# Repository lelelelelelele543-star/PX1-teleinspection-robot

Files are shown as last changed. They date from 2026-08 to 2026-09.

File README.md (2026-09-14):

# PX-1 Teleinspection Robot

## Текущий комплект

Единственный действующий master и документация: [current/](current/README.md).

Механический эталон — Proteus CRP-150. Электроника собственная, на готовых модулях. Текущий статус: **HOLD — рабочая конструкция к изготовлению не выпущена**. Успех CAD-экспорта не означает PASS механики.

- [Общий STEP](current/CAD/PX1_Current_Master.step)
- [Текущая BOM](current/PX1_Current_BOM.csv)
- [Validation](current/PX1_Current_Validation.json)
- [Чертежи и CAD-виды](current/PX1_Drawings_Current.pdf)
- [PDF-документация](current/PX1_Documentation_Current.pdf)
- [Электрические соединения и распиновки](current/ELECTRICAL_Current.md)
- [Сборка, герметизация и испытания](current/ASSEMBLY_AND_TESTS_Current.md)
- [Источники размеров](current/SOURCE_REGISTER.md)
- [Журнал изменений](current/PX1_Change_Log.md)

Шесть колёс; станции X50/X150/X250; десять Z50; два двигателя; Z16→Z40→задняя ось→Z50. Ручной лифт, отдельная герметичная камера, съёмный PRESSURE/LIFT. Оба кабеля ровно шестижильные; основной tether без коаксиала. Своей PCB, кассет и внешних шарниров открытия корпуса нет.

Предыдущие Rev и WB сохранены как история. Их пометки active/PASS не имеют приоритета над current. Перед любым изготовлением сверять HOLD и исходный SHA в validation.

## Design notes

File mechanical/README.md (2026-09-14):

# PX-1 Mechanical CAD — current Rev.B

The controlling mechanical artifact is now one integrated crawler master rather than a chain of exploratory sub-studies.

## Current master

- engineering note: `PX1_CURRENT_MASTER.md`
- executable CAD: `cadquery/PX1_Current_Master_RevB.py`
- executed check: `cadquery/PX1_CURRENT_MASTER_VALIDATION.json`
- generated output: `PX1_RevB_Current_Master.step`

Status: **PASS_INTEGRATED_MASTER / WHEEL_GEOMETRY_DN150_HOLD / PRESSURE_TEST_HOLD / PROCUREMENT_HOLD**.

## Hard crawler architecture

- 3 wheel stations per side / 6 wheels total;
- X50 / X150 / X250;
- five m1 Z50 gears per side / ten total;
- two traction motors total;
- rear X250 long axle is the drive input on each side;
- manual camera lift;
- dry pressurized crawler body;
- separately sealed removable camera;
- no mechanical cassette/cartridge architecture.

## Source-derived assembly

The current master combines the recovered Proteus logic in one model:

- `DRW-002-374` side drive;
- `DRW-002-375` crawler housing / Z40 input / seals;
- `DRW-002-386` two-motor Z16 input;
- `DRW-002-744` manual lift / 150 N gas spring principle;
- `DRW-002-745`, `DRW-002-752`, `ASS-002-890` pressure/lift/camera service interface;
- `ASS-002-090`, `ASS-002-364` rear connector and cable strain-relief logic;
- `ASS-002-103` wheel lock assembly.

Where an original proprietary component is unavailable, the replacement is fitted into the same functional location rather than inventing a different crawler architecture.

## Current geometry

- body main screen 307 x 92 mm;
- rear motor housing end X384;
- wheel stations X50/X150/X250;
- Z50 stations X50/X100/X150/X200/X250;
- lift pivot X200;
- lift pivots Z92/Z109;
- links 90 mm;
- arm planes Y±31 mm;
- camera shell Ø52 x 78 mm;
- service cover 86 x 44 x 6 mm;
- opening 48 x 22 mm;
- flush pressure cap envelope Ø12 x 1.5 mm;
- M12 harness gland horizontal;
- camera harness exactly 6 insulated conductors, hard OD max 6.5 mm;
- lift harness guard envelope 10 mm.

## Six-core camera/lift interface

Exactly:

`+12V / GND / UART TX / UART RX / CVBS signal / CVBS return`.

Dry connector candidate: Molex Micro-Fit 3.0 six-way.

Wet camera connector: WEIPU SP13 six-pin.

No 8-core wet lift harness is controlling.

## Wheel rule

The master displays simple Ø90 x 16 cylinders only as visual wheel placeholders. They are not a valid production tire/profile solid and are excluded from final DN150 geometry release.

MiniCam currently specifies `QRW90SR/150` 90 mm wheels for 150 mm pipe. Final wheel release requires the purchased/measured wheel or exact missing outer-profile drawing/solid plus a physical DN150 jig.

Do not redesign the crawler around the simple cylinder proxy.

## Release rule

The integrated master is suitable for continuing design and prototype packaging, not for machining release.

Before manufacturing release it still needs:

- exact wheel profile;
- matched Z16/Z40 bevel hardware;
- exact pressure seal groove from the real elastomer;
- pressure decay/submersion test;
- six-core cable flex/EMC test;
- physical connector pin orientation;
- exact rear tether-tail dimensions;
- physical DN150 validation.

Historical WBxx files remain in the repository only as calculation/revision traceability. New work should update the current integrated master rather than creating a new crawler architecture.

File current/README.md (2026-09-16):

# PX1 Current

Единственный текущий комплект. Механический эталон Proteus CRP-150; собственная электроника на готовых платах.

## Rev.A fast-track

**Rev.A обязательно шестиколёсный. 4-колёсный вариант не является допустимым упрощением.**

Активный порядок разработки описан в [REV_A_FAST_TRACK.md](REV_A_FAST_TRACK.md).

Рабочие пакеты:
- [00_PROJECT_CONTROL](00_PROJECT_CONTROL/README.md)
- [01_MECHANICAL_6X6](01_MECHANICAL_6X6/README.md)
- [02_ELECTRICAL](02_ELECTRICAL/README.md)
- [03_FIRMWARE](03_FIRMWARE/README.md)
- [04_CAMERA_HEAD](04_CAMERA_HEAD/README.md)
- [05_TETHER_REEL](05_TETHER_REEL/README.md)
- [06_CONSOLE](06_CONSOLE/README.md)
- [07_TESTS](07_TESTS/README.md)
- [08_PROCUREMENT](08_PROCUREMENT/README.md)
- [09_RELEASE](09_RELEASE/README.md)

## Current engineering baseline

- CAD/PX1_Current_Master.py — единственный исходник текущей сборки.
- CAD/PX1_Current_Master.step — экспорт после успешной сборки.
- PX1_Current_BOM.csv — единая BOM.
- PX1_Current_Validation.json — проверка конкретного экспорта; старые результаты не переносить.
- PX1_Change_Log.md — единый журнал изменений.
- SOURCE_REGISTER.md — источники размеров и границы достоверности.
- ELECTRICAL_Current.md — схемные соединения и логические распиновки.
- ASSEMBLY_AND_TESTS_Current.md — герметизация, давление, сборка, обслуживание, испытания.
- PX1_Drawings_Current.pdf / PX1_Documentation_Current.pdf — текущие документы.

Frozen crawler architecture: six wheels; stations X50/X150/X250; ten Z50 total; two traction motors; Z16→Z40→rear X250 axle→Z50 train. Manual lift, separately sealed camera, reinforced six-core main tether without coax, no custom main PCB required for the first prototype.

`Metal_HOLD` and unresolved CAD remain prototype-only. A successful CAD export is not an engineering PASS. Historical WB/Rev files are retained as history and cannot override `current/`.

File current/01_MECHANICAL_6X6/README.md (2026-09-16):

# 01 MECHANICAL — 6×6 CRAWLER

Scope: body, side drives, shafts, gears, bearings, seals, six wheels, motor mounting, manual lift mechanical interfaces.

Frozen topology: 3 wheel stations per side at X50/X150/X250; 5×Z50 per side; rear X250 driven input; two motors total; Z16->Z40 bevel input.

Immediate work:
1. lock motor mounting that physically fits the recovered Proteus envelope;
2. lock Z16/Z40 matched bevel pair and mounting distance;
3. finish shaft/bearing stack dimensions;
4. produce printable/fabricable A0 drivetrain bench parts;
5. assemble full six-wheel rolling chassis only after A0 passes.

Do not release metal machining while any critical shaft, gear mesh, bearing seat or seal groove dimension is HOLD.

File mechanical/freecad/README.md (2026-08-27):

# FreeCAD workflow for PX-1

## First model
1. Open FreeCAD and create a new document.
2. View -> Panels -> Python console.
3. Run `PX1_Master_Parameters.py`.
4. Run `PX1_Body_Master.py`.
5. Save as `PX1_MASTER.FCStd`.

The model is parameter-driven. Change dimensions on the `PX1_Parameters` object instead of editing geometry directly.

## Frozen prototype baseline
- body 250 x 94 x 76 mm
- wheelbase 160 mm
- wheel diameter 90 mm
- front axle X=45 mm
- rear axle X=205 mm
- axle Z=37 mm
- only two rear rotating body penetrations
- rear carrier bore Ø38 mm
- shaft Ø10 mm
- 6000 bearing: 10 x 26 x 8 mm
- seal: 10 x 22 x 7 mm

## Important
The rear LEMO opening in this model is only the controlled nominal interface envelope. Do not use generated thread geometry as a substitute for the official connector machining requirements.

Next FreeCAD components will be linked to the same master parameter object: rear carrier, output shaft, front stub axle, drivetrain gears, wheel, motor cradle, camera lift and camera head.

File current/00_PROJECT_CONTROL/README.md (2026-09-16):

# 00 PROJECT CONTROL

Single control point for PX1 Rev.A.

Authoritative working plan: `../REV_A_FAST_TRACK.md`.

Rules:
- 6×6 architecture is frozen;
- `current/` is the only active product set;
- historical WB/Rev files are evidence/history, not controlling geometry;
- every unresolved manufacturing dimension remains HOLD;
- every change that affects interfaces is recorded in `../PX1_Change_Log.md`;
- do not start a new concept to bypass a difficult detail.

Stage gates: A0 drivetrain bench -> A1 rolling chassis -> A2 tether -> A3 camera/lift -> A4 demo -> A5 endurance -> A6 production release.

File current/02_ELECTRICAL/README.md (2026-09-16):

# 02 ELECTRICAL

Scope: 24 V input, DC/DC rails, traction drivers, MCU, RS-485, pressure sensing, lighting supply/control, camera power/video interfaces, protection and connectors.

Prototype principle: ready-made serviceable modules, no custom main PCB required.

Immediate work:
1. bench power tree;
2. two traction channels under real motor load;
3. RS-485 command link;
4. emergency/communication-loss motor stop;
5. pressure input;
6. camera + lighting integration;
7. 40 m tether voltage-drop/EMC test.

Existing `../ELECTRICAL_Current.md` remains the detailed electrical reference until replaced by verified measurements.

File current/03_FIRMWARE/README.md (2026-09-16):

# 03 FIRMWARE

Rev.A firmware is intentionally minimal.

First required functions:
- forward/reverse;
- differential steering;
- speed command;
- traction stop on lost communications;
- light level command;
- pressure telemetry;
- basic fault/status telemetry.

After the crawler physically drives through the tether, add distance/OSD/operator conveniences. Do not block A0/A1 mechanics waiting for advanced UI features.

Recommended split:
- `crawler/` — STM32 traction/telemetry firmware;
- `console/` — operator controls/protocol;
- `protocol/` — one documented RS-485 packet definition shared by both ends.

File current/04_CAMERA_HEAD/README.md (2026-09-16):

# 04 CAMERA HEAD + MANUAL LIFT

Scope: sealed camera head, CVBS module, white LEDs, local six-conductor harness, PAN/ROTATE only when required by the selected head implementation, and manual Proteus-style lift.

Fast-track requirement: a stable forward inspection image is more important than completing every final camera feature before A4.

Gate for A3:
- stable image under traction motor operation;
- usable illumination;
- separately sealed/removable head;
- low/high manual lift positions;
- harness routing survives repeated movement without pinching or rubbing.

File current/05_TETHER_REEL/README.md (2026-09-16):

# 05 TETHER + REEL

Main tether architecture is frozen: professional reinforced six-core copper inspection cable, no coax in the main tether, field-reterminable, tensile load carried mechanically rather than by contacts.

Fast-track:
- first system length: 40 m;
- qualify conductor resistance, loaded voltage drop, RS-485 and video behaviour before 100–150 m design;
- temporary/manual cable handling is acceptable for A4 if safe and reliable.

RMP300-style reel, levelwind, brake, measuring wheel and slip ring are retained as the production direction but may not block first crawler demonstration.

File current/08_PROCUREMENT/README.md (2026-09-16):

# 08 PROCUREMENT

Procurement is stage-driven.

Buy first only what is required for A0/A1/A2:
- two traction motors matching the selected mount;
- matched bevel gears/shaft hardware;
- Z50 gears or fabrication material;
- bearings/bushings/seals for one complete crawler;
- six wheel samples/approved wheel solution;
- MCU + two traction drivers + RS-485 + DC/DC/protection;
- enough six-core tether for the 40 m prototype plus termination allowance.

Camera/reel/production cosmetics are second wave unless needed to unblock interface dimensions.

Every ordered item must be entered in `../PX1_Current_BOM.csv` with exact article, quantity, dimensions/source and its release/HOLD state.

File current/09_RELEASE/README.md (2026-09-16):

# 09 RELEASE

This folder is the gate to fabrication/production, not a dumping ground for experimental CAD.

A6 release requires:
- proven 6×6 crawler geometry;
- exact bought-part articles and measured/official envelopes;
- no critical machining dimension marked HOLD;
- released STEP/STL and part drawings;
- released BOM;
- electrical pinout and wiring;
- firmware version/protocol reference;
- assembly/disassembly procedure;
- sealing procedure;
- test acceptance sheet.

Until these conditions are met, project status remains prototype/HOLD.

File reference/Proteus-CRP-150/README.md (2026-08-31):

# Proteus CRP-150 reference reconstruction

Status: active engineering reference, revision 0.1, 2026-08-31.

This directory collects verified information about the Mini-Cam Proteus CRP-150 crawler system and separates it from the PX1 replacement design. Its purpose is to preserve the proven Proteus architecture while identifying replacements that can be purchased, machined, printed and serviced without proprietary Mini-Cam parts.

## Project rule

Every statement is assigned one of four evidence states:

- `CONFIRMED-DRAWING` - explicitly shown in an available source drawing or parts list;
- `CONFIRMED-PHOTO` - visible in repair photographs or video;
- `RECONSTRUCTED` - derived from several confirmed facts and engineering geometry;
- `PROVISIONAL` - a candidate that still requires measurement or a bench test.

Original Mini-Cam drawings are not stored here. The available drawings contain restrictions on copying and distribution, and this repository is public. This directory stores source identifiers, engineering facts, calculations and original reconstruction work only.

## System map

| Subsystem | Original reference | Replacement goal | Current state |
|---|---|---|---|
| Crawler body and drive | CRP-150 / X200 | Preserve six-wheel, five-gear side drive and two-motor bevel input | Drive architecture confirmed |
| Manual lift | CRP-150 lift | Preserve manual lift, 150 N spring and M8 clamp | Source set identified |
| Camera | CAM026 | Preserve sealed PAN/ROTATE behavior with available camera and motors | Pending detailed reconstruction |
| Cable reel | RMP300 | Preserve manual drum, brake, level wind, measuring wheel and slip ring | Source set identified |
| Control unit | Proteus portable control unit | Rebuild from replaceable 24 V modules | Functional requirements established |
| Tether | Proteus inspection cable | Reinforced, field-repairable six-core copper cable | Architecture fixed; conductor sizing pending |

## Directory map

- [`SOURCE_REGISTER.md`](SOURCE_REGISTER.md) - source identifiers and evidence limits;
- [`VERIFICATION_REGISTER.md`](VERIFICATION_REGISTER.md) - open measurements and proof status;
- [`crawler/DRIVE_ARCHITECTURE.md`](crawler/DRIVE_ARCHITECTURE.md) - confirmed CRP-150/X200 drive reconstruction;
- [`crawler/GEAR_AND_SHAFT_AUDIT.md`](crawler/GEAR_AND_SHAFT_AUDIT.md) - calibrated gear geometry and CAD conflict audit;
- [`replacement-parts/STRATEGY.md`](replacement-parts/STRATEGY.md) - rules and first replacement matrix;
- `cad/reconstruction/` - only original reconstruction CAD, never copied factory drawings;
- `camera/`, `lift/`, `reel/`, `control-unit/` - subsystem work areas.

## Fixed project constraints

- preserve the successful Proteus mechanical architecture unless availability, serviceability, cost, reliability or manufacturability justifies a change;
- use integrated serviceable assemblies, not cartridge or cassette concepts;
- prototype electronics use ready-made modules; no custom main PCB;
- internal robot power is 24 V class;
- main tether is one professional reinforced six-core copper inspection cable;
- no coaxial main cable, no optical fiber and no bundle of loose ordinary twisted pairs;
- keep a universal sealed quick-release tail connection with a separate mechanical strength path;
- do not release machining drawings until one side drive, one camera axis and the reel counter mechanism are physically proven.

## Current priority

1. Complete the original crawler skeleton and shaft stack.
2. Select an available 24 V traction motor that preserves the Z16 to Z40 input.
3. Validate the five-Z50 side drive and wheel speed.
4. Reconstruct the manual lift.
5. Continue with CAM026, RMP300 and the control unit.

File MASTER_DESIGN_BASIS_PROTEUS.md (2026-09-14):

# PX-1 MASTER DESIGN BASIS — Proteus CRP-150 replacement system

Status: ACTIVE MASTER DIRECTIVE.

## Mission
Build a serviceable, lower-cost teleinspection system that preserves the proven MiniCam Proteus CRP-150 / CAM026 / RMP300 user experience and mechanical logic while replacing proprietary, obsolete, expensive or hard-to-source parts with readily available equivalents.

This document supersedes earlier experimental PX1 concepts where they conflict with the Proteus-reference architecture.

## System-level rule
Preserve where possible:
- crawler external form and DN150-class packaging;
- six-wheel crawler layout;
- three driven wheel stations per side;
- five equal side gears per side;
- rear wheel long-axle input architecture;
- Z16 -> Z40 bevel input with two motors total;
- manual camera lift with 150 N gas spring and M8 clamp;
- compact removable pressure/lift service interface with local cable gland and protected camera harness;
- CAM026-like 360-degree ROTATE and +/-135-degree PAN envelope/function;
- lightweight manual RMP300-style reel with level-wind, brake, measuring wheel and slip-ring path;
- simple portable control console workflow.

Change where needed:
- motors;
- controller electronics;
- motor drivers;
- video electronics;
- pressure sensor electronics;
- connectors;
- slip ring;
- distance encoder;
- bearings/seals only when original sizes are unavailable or a direct standard replacement is preferable;
- camera imaging module and focus system.

## Crawler baseline
Source references: DRW-002-374, DRW-002-375, DRW-002-386.

Active side-drive topology, each side:
- wheel Z50;
- idler Z50;
- wheel Z50;
- idler Z50;
- driven rear wheel Z50 on long axle.

The rear wheel is the driven input station. There is no separate fourth input shaft.

Source bearing/seal architecture per side:
- 1x 61801-class bearing on long-axle/input path;
- 3x 61903-class wheel bearings;
- 3x X-ring 18.72x2.62;
- 3x static axle-flange O-rings 32x1.5;
- side-cover O-ring 190x1.5;
- two small idler bushings 10-12-4.

Main crawler body source architecture:
- 2x Z40 large bevel gears;
- 2x 18x30x7 shaft seals;
- 2x 61800 10x19x5 bearings;
- lift holding/axle parts integrated into body.

Motor unit source architecture:
- 2 motors total;
- 2x Z16 small bevel gears;
- 2x supported bevel pinion shafts;
- 2x 61801 bearings.

Official CRP-150 control envelope used as target reference: about 307 x 133 x 110 mm.

## Manual lift baseline
Source: DRW-002-744.

Retain:
- 1x gas spring 150 N;
- 2 side levers;
- lever sheet plate;
- M8 clamping lever;
- Belleville spring stack;
- source-style axle/washer/circlip arrangement.

Do not invent new powered lift mechanisms unless the manual source architecture proves impossible to reproduce.

## Pressure/lift service interface baseline
Sources: DRW-002-745, DRW-002-752, ASS-002-890, DRW-003-121 / ASS-003-121 and CRP150 repair photographs.

Retain the functional logic:

`dry pressure body -> removable sealed service cover/lift housing -> compact pressure/fill valve -> local M12-class cable gland -> short protected camera harness -> removable camera connector`.

Current PX-1 Rev.B implementation is controlled by WB23E/F/G:

- WB22A hard lift geometry remains unchanged;
- body lift pivot remains X200;
- no mandatory dual flex chambers or energy-chain style loops;
- service cover is WB23E 86 x 44 x 6 mm with 48 x 22 mm opening and two-M4 prototype retention;
- pressure-port procurement follows WB23F: preferred exposed valve+cap envelope <=Ø12 x 5 mm, current hard screen <=Ø14 x 6 mm;
- local wet camera/lift harness is exactly **six insulated conductors**: +12V, GND, UART TX, UART RX, CVBS signal, CVBS return;
- overall cable shield is EMC only and never DC power return;
- local cable target is 6 x 0.25 mm² class, preferred OD 5.5...6.0 mm, hard packaging maximum 6.5 mm;
- lower-arm cable is protected by a simple removable drain-open guard; WB23G conservative guard envelope is 10 mm;
- free slack at the two moving ends is physically qualified rather than represented by invented constant-radius CAD loops;
- gland seals the cable jacket through the pressure boundary but is not the electrical disconnect;
- dry internal connector is six-way so the complete external cover/gland/harness assembly can be replaced without dismantling main electronics;
- external removable camera uses the controlled six-function SP13 interface.

Historical WB21/WB23A local cable studies, including Ø8/8-core concepts, are archived only and do not control current wiring, procurement or mechanical packaging.

The exact original Proteus small pressure-cover screw count is not source-confirmed. PX-1's two-M4 compact service cover is an independent prototype decision and must pass pressure/seal/alignment tests.

## Camera baseline
Source family: CAM026 assembly drawings.

Target reference function/envelope:
- CAM026-like external form;
- continuous 360-degree ROTATE;
- PAN +/-135 degrees;
- roughly 75-degree forward FOV class;
- two clusters of 3 white LEDs around the lens;
- separately sealed camera module.

Simplification:
- delete proprietary motor-control PCBs;
- delete proprietary focus motor/gear/PCB;
- use a fixed-focus modern camera module/lens where practical;
- use standard replaceable motor driver modules;
- use an off-the-shelf slip ring sized for required circuits;
- retain mechanical sealing/axis logic where practical.

## RMP300 reel baseline
Source family: ASS-004-097 and child assemblies.

Retain:
- manual drum;
- 160 mm crank handle;
- mechanical brake;
- 272 mm level-wind spindle;
- main reel shaft/slip-ring path;
- measuring roller assembly;
- mechanical level-wind driven from drum motion;
- lightweight portable frame concept.

Simplify:
- no reel drive motor;
- delete proprietary meter-counter PCB;
- replace distance pickup with a standard magnetic or optical encoder module;
- replace proprietary 12-pole slip-ring/PCB arrangement with a readily available serviceable slip ring matched to PX1 tether current/voltage/circuit needs.

## Tether
Use one professional reinforced six-core copper inspection cable, Proteus-like in principle:
- no coax;
- no optical fiber;
- no bundle of ordinary loose twisted pairs;
- aramid/Kevlar strength path separate from electrical contacts;
- field-repairable/reterminable.

Initial length: 40 m. Longer 100-150 m versions are accepted only after real conductor-resistance and cable-loss measurement.

The six-core main tether and the six-core local camera/lift harness are different physical cables/interfaces but deliberately retain a simple six-circuit philosophy where practical.

## Electronics philosophy
No custom main PCB for the prototype.
Use standard, replaceable modules and simple wiring:
- MCU/controller module;
- two traction H-bridge channels;
- camera PAN/ROTATE driver channels;
- RS-485;
- pressure sensor;
- video interface;
- simple DC/DC conversion as required;
- encoder inputs for distance/odometry.

The electronics must be cheaper and easier to replace than original Proteus P01/CAM/reel boards.

## Release rule
No feature is added merely because it is technically interesting. A deviation from Proteus must have a clear benefit in at least one of:
- availability;
- cost;
- field repairability;
- manufacturing simplicity;
- reliability.

If the original Proteus mechanical solution already works well and can be reproduced economically, keep it.

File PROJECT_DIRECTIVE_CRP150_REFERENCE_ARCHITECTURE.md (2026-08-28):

# PX-1 — CRP-150 reference architecture directive

Status: ACTIVE PROJECT DIRECTION. This directive supersedes any tendency to redesign proven Proteus mechanisms without a clear sourcing/service reason.

## Mission
Build a teleinspection system that preserves the successful working concept, proportions, ergonomics and service behavior of MiniCam Proteus CRP-150, while replacing unavailable, obsolete, expensive or proprietary parts/electronics with readily obtainable and field-serviceable alternatives.

The target is NOT to invent a new crawler architecture. The target is a practical CRP-150-like system that can be maintained from accessible parts.

## What should stay as close as practical to Proteus
### Crawler
- overall CRP-150 style body form and six-wheel layout;
- side geared drivetrain concept;
- wheel positions/stance and low DN150 operating posture;
- manual lift concept and camera placement;
- open forward camera area in LOW position so the camera still sees ahead and wastewater cannot be trapped in a cup/pocket;
- pressurized dry body and serviceable sealing architecture;
- tail/cable strain-relief philosophy.

### Camera
- compact sealed rotating camera head concept;
- useful picture when folded LOW;
- rotation/tilt behavior close to the original operating experience;
- serviceable optical window, lighting and seals;
- proprietary camera electronics may be replaced with simple available video/control hardware.

### Reel
- lightweight mobile manual Proteus/RMP-style reel;
- manual crank, brake, level wind and measuring wheel/counter concept;
- compact frame and easy transport are preferred over powered reel complexity.

### Control unit
- preserve the simple Proteus operator workflow: monitor, joysticks/controls, distance indication, crawler drive, camera motion and lights;
- replace proprietary high-cost control electronics with modular readily available electronics;
- prototype should avoid a custom main PCB where possible.

## What is allowed to change
Change a Proteus detail only if at least one condition is true:
1. original spare part is unavailable or excessively expensive;
2. original part is known to be a recurring repair problem;
3. a standard bearing/seal/motor/connector/module can provide the same function with easier service;
4. the original electronics can be replaced by simpler modular control without changing the operator experience;
5. safety, ingress protection or manufacturability requires the change.

Any such change must preserve the mechanical/functional role of the original part as closely as practical.

## Source hierarchy
Before inventing a PX-1 mechanical solution, check the uploaded MiniCam drawings first.
Useful confirmed source groups already present in the project files include:
- CRP crawler/lift parts drawings such as DRW-002-744 / DRW-002-752 / DRW-002-745;
- CAM026 camera assembly ASS-001-801 / ASM001 and rotate-seal assembly ASS-002-004;
- Proteus cable-end socket ASS-003-215 and related connector drawings;
- RMP300 manual reel assembly ASS-004-097, reel halves ASS-004-094/095, core ASS-004-093, meter counter ASS-004-092 and reel handle ASS-002-712.

Use these documents as the primary architecture reference. Do not create extra pods, special drainage structures, nonstandard mechanisms or complex electronics merely because they are theoretically possible if the Proteus arrangement already solves the same problem more simply.

## Replacement philosophy
Preferred replacements:
- standard metric bearings and seals;
- generic 24 V DC gearmotors with measurable specifications;
- standard industrial waterproof connectors;
- STM32/other common controller modules;
- simple dual H-bridge motor drivers;
- RS-485 for commands/telemetry;
- balanced analog video over the selected 6-core inspection tether;
- common CVBS monitor/OSD/DVR modules;
- standard encoders/measuring wheel for distance.

Keep replacements modular and replaceable with ordinary workshop tools.

## Cable constraint
Main tether remains one Proteus-style reinforced 6-core copper inspection cable. No coaxial main conductor architecture, no optical fibre replacement and no bundle of separate ordinary twisted-pair cables.

## Design rule going forward
For every subsystem use this sequence:
1. reproduce/understand the Proteus source mechanism from uploaded drawings;
2. identify which original parts are actually unavailable/proprietary/expensive;
3. substitute only those parts;
4. keep the rest of the geometry and function as close to the proven Proteus arrangement as practical;
5. validate DN150 fit, sealing, service access and manufacturability.

## Immediate reset of current work
- treat the recent highly modified wet-deck/controller-saddle concepts as exploratory only, not the new design target;
- return the crawler nose/lift/camera packaging to the closest practical CRP-150 geometry supported by the uploaded drawings;
- rebuild the CAD viewer from this CRP-150-reference baseline;
- develop crawler, camera, reel and control unit as one matched system, not as unrelated redesigns.

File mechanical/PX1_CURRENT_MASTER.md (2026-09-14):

# PX1 Current Master

**Date:** 2026-09-14  
**Controlling assembly:** `PX1_Current_Master.step` in the current release pack  
**Status:** `HOLD / NOT_FINAL_MACHINING_OR_FULL_DN150_RELEASE`

Proteus CRP-150 remains the primary mechanical reference. This is the single active PX1 integration state; old WB/Rev files are historical evidence only. A HOLD proxy is never treated as a manufacturing PASS.

## Frozen architecture

- 6 wheels at X50 / X150 / X250, mirrored left/right.
- 5 x Z50 per side at X50 / X100 / X150 / X200 / X250; adjacent centers 50 mm; rear X250 driven.
- Two traction motors total; motor -> supported Z16 -> Z40 -> rear axle -> five-Z50 train.
- Dry positively pressurized body; dynamic wheel sealing by X-rings; Z40 body shafts by 18x30x7 seals.
- Manual one-hand parallelogram-like camera lift; camera is separately sealed and removable.
- Removable PRESSURE/LIFT service cover with compact pressure valve and M12 camera-cable gland.
- Local camera harness exactly six insulated conductors: +12V, GND, TX, RX, CVBS signal, CVBS return.
- Main tether exactly six copper cores: HV+, HV return, RS485_A, RS485_B, VIDEO+, VIDEO-. Aramid/Kevlar is mechanical only.
- No coax in the main tether, no fibre, no custom PCB in the prototype, no cassette/cartridge mechanics, no external pressure-body hinges.

## Corrected drivetrain source content

Current master contains 12 x 61801 in the two side drives (6 per side), plus 2 x 61801 supporting the Z16 input shafts. Also present: 6 x 61903, 6 x X-ring 18.72x2.62, 2 x 61800, 2 x 18x30x7 shaft seals, 10 x Z50, 2 x Z16 and 2 x Z40.

## CAM026 camera evidence incorporated 2026-09-14

User teardown photos/video have been incorporated into the current camera reference. The previous ~Ø52 camera proxy is retired.

Confirmed / directly observed:
- lower/base cylinder outer diameter approximately **62.5 mm** from a caliper photo;
- hollow central wiring path through the rotating output;
- large internal ring-gear output driven by a smaller pinion;
- multi-stage reduction;
- thrust-bearing/race stack carrying axial load.

The current release-pack STEP uses ~62.5 mm as the CAM026-derived camera base-OD integration screen and contains reference solids for the hollow rotor, internal ring gear, thrust-bearing stack and reduction concept. Internal fits, wall thickness, tooth geometry and seal-groove dimensions remain HOLD. No further user teardown measurements are required; those items must be closed by controlled drawings, supplier samples or prototype work rather than invented values.

## Current validation facts

- 6 wheels / 10 Z50 / 12 side-drive 61801 / 6 61903 / 6 X-rings / 2 Z40 / 2 Z16 / 2 Z16-support 61801 / 2 motors / exactly 6 camera conductors.
- No invalid CAD shapes in the current generated assembly.
- Service-vs-Z50, service-vs-lift, service-vs-camera and motor-vs-camera modeled intersections: 0 mm³.
- Electronics pairwise intersections: none in the modeled envelopes.
- Ideal-DN150 non-wheel screen: pressure body about +1.01 mm, service cover +6.42 mm, pressure valve cap +8.28 mm, LAPP gland +13.75 mm, camera LOW +20.80 mm, rear connector panel +44.51 mm.
- **Full DN150 vehicle remains HOLD** pending the actual QRW90SR/150 wheel profile/hub and a real rigid-pipe test.

## Current real/published components represented

- ISL PGM-32P-24-100-60-02: 24 V, Ø32 mm, published length 92 mm, 100:1, 60 rpm no-load.
- NBK MLR-20C-6-6: Ø20 x 24 mm, 6/6 bores.
- LAPP 53112000 SKINTOP MS-M 12x1.5: M12x1.5, clamp 3.5-7 mm, ØA17.6, Cmax26.5, thread 6.5 mm.
- Cincon CQB150W-110S24: 57.9 x 36.8 x 12.7 mm.
- Adafruit MPRLS Product 3965: 17.8 x 16.7 x 7.5 mm, 0-25 PSI absolute.
- Nichicon UCS2D221MHD1TN: 220 uF / 200 V, Ø18 x 25 mm.
- WEIPU SP13 six-way camera connector family; sample/detail gate remains.
- WEIPU SP17 rear connector family; current architecture uses 7 contacts with exactly 6 tether cores and one unused spare.

## Current files

- `mechanical/cadquery/PX1_Current_Master_RevB.py` - earlier GitHub executable source retained for history/reference; the exact generator used for the current binary master is distributed in the release pack as `PX1_Current_Master.py`.
- `mechanical/cadquery/PX1_CURRENT_MASTER_VALIDATION.json` - current validation, synchronized with the current release pack.
- `mechanical/PX1_CURRENT_CRAWLER_BOM_RevB.md` - current BOM mirror.
- `mechanical/PX1_CHANGE_LOG.md` - current change journal.
- `electrical/PX1_Current_Electrical_Pressure_Pinouts.md` - electrical / pressure / pinout specification.
- `mechanical/PX1_Current_Manufacturing_Assembly_Test.md` - manufacturing, assembly and test sequence.

Binary STEP/PDF/STL deliverables and the exact current generator are distributed in the release ZIP. GitHub text specifications and validation are synchronized to this release.

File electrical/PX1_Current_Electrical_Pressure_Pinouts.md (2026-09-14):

# PX1 Electrical / Pressure / Pinouts - Current

## Main tether - exactly 6 copper conductors

| Core | Function |
|---:|---|
| 1 | HV+ |
| 2 | HV return |
| 3 | RS485_A |
| 4 | RS485_B |
| 5 | VIDEO+ |
| 6 | VIDEO- |

Aramid/Kevlar is mechanical only and is never an electrical conductor. The main tether contains no coaxial core and no fibre.

## Local camera harness - exactly 6 insulated conductors

| Pin | Function |
|---:|---|
| 1 | +12V_HEAD |
| 2 | GND_HEAD |
| 3 | TX |
| 4 | RX |
| 5 | CVBS signal |
| 6 | CVBS return |

The CAM026 teardown showed six visible contact pads on one interface board, but pad count is evidence only; PX1 electrical functions are not inferred from that board.

## Power chain

```text
surface HV source / hardware E-STOP
 -> 6-core tether HV+ / HV return
 -> rear sealed connector + separate mechanical strain relief
 -> fuse / transient / inrush protection
 -> Cincon CQB150W-110S24
 -> 24 V bus
    -> LEFT BTS7960 -> left traction motor
    -> RIGHT BTS7960 -> right traction motor
    -> 24->12 V camera / lighting branch
    -> 12->5 V logic / sensor branch
    -> STM32 NUCLEO-F446RE
    -> MAX485 interface
```

Current rear connector architecture: WEIPU SP17 family with 7 contacts, exactly 6 tether cores used and one contact left unused/spare. The connector contacts carry no towing load.

## Video path

```text
camera CVBS signal/return
 -> short local six-core harness
 -> crawler video interface/balun
 -> tether VIDEO+/VIDEO-
 -> reel/pass-through
 -> surface receiver / OSD
 -> 7 in CVBS monitor
```

## Pressure chain

```text
external compressor/service fill adapter
 -> compact spring/ball pressure valve
 -> common dry crawler pressure volume
 -> Adafruit MPRLS Product 3965 absolute-pressure sensor
 -> STM32
 -> RS-485 telemetry
 -> control-unit pressure display
```

MPRLS current reference: 17.8 x 16.7 x 7.5 mm, absolute 0-25 PSI. Firmware records ambient absolute pressure immediately before pressurisation and displays the gauge delta.

Primary sealing paths:
- body/service cover: static elastomer face seal; final groove HOLD;
- six wheel stations: X-ring 18.72 x 2.62 plus static flange seal family;
- two Z40 body paths: 18 x 30 x 7 rotary shaft seals;
- camera: separate sealed pressure body;
- camera cable entry: LAPP 53112000 M12x1.5 gland;
- rear tether: sealed bulkhead plus independent mechanical strength termination.

## Safety states

- loss of valid control/heartbeat -> traction STOP;
- MCU reset -> traction STOP;
- overcurrent/jam -> affected traction channel STOP;
- pressure outside configured band -> fault/stop policy;
- hardware E-STOP removes tether HV independently of crawler firmware;
- no automatic restart after a safety trip.

Acceptance still requires +0.25 bar decay and submerged bubble testing, plus simultaneous motor + RS-485 + CVBS testing on the real 40 m tether before any 100-150 m release.

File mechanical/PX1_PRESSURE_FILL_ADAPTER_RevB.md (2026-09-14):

# PX-1 pressure fill / purge adapter — Rev.B WB24A

Date: 2026-09-14
Status: **SERVICE TOOL PROTOTYPE / THREAD + STROKE HOLD**

The adapter is a removable workshop/field tool. It is never installed while driving the crawler and therefore does not belong to the DN150 moving envelope.

## Purpose

One tool must allow the technician to:

- screw onto/into the low-profile PX1 PRESSURE port after removing the protection cap;
- mechanically open the internal valve positively;
- connect a regulated air / CO2 / nitrogen source;
- monitor pressure through the crawler pressure sensor/control display;
- purge pressure back to ambient before opening the service cover.

This follows the documented Proteus operating logic: remove protection cap, screw on pressure adaptor, fill, remove adaptor, refit cap. A purge screw is also documented on the Proteus Ex pressure-valve tool.

## Prototype interface

Crawler-side thread candidate:

- `M8 x 1` male nose on adapter;
- engagement target around 4–5 mm;
- thread remains prototype only until the actual valve stack is bench-tested.

Opening probe:

- central stainless probe;
- adjustable effective protrusion by replaceable shim/stop during first bench development;
- prototype opening stroke target only ~0.5...1.0 mm;
- rounded probe end; no sharp point against valve shaft/ball;
- positive shoulder prevents over-stroking the internal valve.

Gas passage:

- axial bore around/through probe arrangement;
- cross drillings downstream of thread seal so gas reaches valve mouth even while the probe is depressing the check element;
- passage >=1.5 mm class is ample for the small crawler volume and low fill pressure; exact drill is not performance-critical.

## Tool-side connection

Do not hard-code the crawler to one compressor fitting.

Adapter body ends in a standard replaceable pneumatic interface. Prototype choices:

- G1/8 female port plus interchangeable hose nipple/quick coupling; or
- G1/8 port plus a separate tire-chuck/Schrader tool fitting if the user's compressor gun is a tyre inflator.

This keeps all bulky marketplace pneumatic hardware on the removable service tool rather than on the crawler roof.

## Purge function

Preferred adapter includes a small needle/purge screw:

- positioned downstream of the crawler valve so opening it vents crawler pressure while adapter remains screwed in and valve remains mechanically open;
- screw cannot fall out in normal use;
- vent direction points away from the operator's face;
- flow is deliberately modest so pressure can be watched on the control unit while venting.

A simple M4-class needle screw is a prototype concept only; final seat/O-ring/thread geometry follows the actual machined tool.

## Operating sequence

1. crawler OFF for mechanical service, or powered only as required to read pressure safely;
2. clean valve area;
3. unscrew low-profile protection cap;
4. screw WB24A adapter into pressure port until shoulder seats — do not overtighten;
5. close purge screw;
6. connect regulated source;
7. set source regulator to a safe low pressure; never connect bottle/compressor reservoir directly without regulation;
8. fill while watching crawler pressure reading;
9. isolate source;
10. disconnect source hose if desired;
11. for normal operation, unscrew adapter and confirm valve closes without bubbling/leak indication;
12. reinstall clean protection cap.

For depressurisation before service:

1. screw adapter in so valve is mechanically opened;
2. open purge screw slowly;
3. watch pressure fall to ambient;
4. only then loosen the PRESSURE/CAMERA SERVICE cover.

## Safety rule

The adapter is not a pressure regulator. The source must be regulated upstream.

PX1 normal development pressure remains approximately +0.25 bar gauge unless a later controlled pressure specification supersedes it. The service tool should be rated comfortably above the test/proof pressure, but high tool rating does not authorize over-pressurising the crawler.

## Prototype drawings to make after valve bench test

After the winning WB24A valve insert is known, release:

- ADP-PX1-001 adapter body;
- ADP-PX1-002 opening probe;
- ADP-PX1-003 purge screw;
- tool-side G1/8 fitting callout;
- probe-stroke gauge/check dimension.

The adapter must be tested together with the valve; neither is independently released.

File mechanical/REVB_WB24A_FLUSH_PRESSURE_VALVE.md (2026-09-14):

# PX-1 Rev.B WB24A — flush PRESSURE valve / fill interface

Date: 2026-09-14
Status: **SOURCE TOPOLOGY CONFIRMED / PX1 PROTOTYPE ARCHITECTURE SELECTED / LEAK TEST HOLD / MACHINING HOLD**

## 1. Reason for this block

WB23F showed that a conventional exposed pressure valve is the limiting fixed item for LOW / ideal DN150. A Ø14 x 6 mm exposed valve leaves only about 4.70 mm ideal clearance; taller parts quickly consume the margin.

MiniCam source evidence shows that Proteus/CAM026 does not require a permanently tall external Schrader stem. The source architecture uses a compact protected valve with a removable protection cap and a separate screw-on pressure adaptor.

PX-1 will therefore use the same **functional idea**, with independently designed metric parts.

## 2. Confirmed MiniCam source evidence

Repeated source parts across CAM026 / crawler cover assemblies:

- `FSS-001-843` — CAMERA VALVE SHAFT;
- `FSS-001-844` — CAMERA VALVE COVER;
- `BEA-001-845` — 4MM BALL BEARING;
- `SEA-001-846` — 3 x 1 O-RING, quantity 2 in the valve source assembly;
- `SPR-001-847` — VALVE SPRING;
- `SEA-001-848` — 6 x 1.5 O-RING.

A separate MiniCam source BOM identifies `SPR-001-847` as:

- wire diameter `d = 0.5 mm`;
- outside diameter `De = 3.7 mm`;
- free length `L0 = 7.9 mm`.

The individual shaft/cover manufacturing drawings have not been found in the current source set, so **no unshown MiniCam dimension is copied or invented**.

Official Proteus operating instructions independently confirm the service topology:

1. unscrew pressure-valve protection cap;
2. screw on the pressure-valve connection adaptor;
3. fill with regulated CO2/Nitrogen;
4. remove adaptor;
5. refit protection cap.

The Ex instruction also shows a purge screw on the pressure adaptor for controlled depressurisation.

## 3. PX-1 functional architecture

Controlled concept:

`WB23E service cover -> recessed metric service port -> spring/pressure-assisted check element -> removable low-profile protection cap`

Service tool:

`threaded pressure adaptor -> centre opening probe + gas passage -> regulator/hose -> compressor/CO2/N2 source`.

The adapter is present only during servicing and is **not part of the DN150 driving envelope**.

The protection cap is debris protection and a secondary seal. The internal check element is the primary gas-retention device.

## 4. PX-1 prototype geometry — screen values

These are independent PX-1 prototype values, not claimed as original MiniCam dimensions.

### Top service interface

- location retained from WB23E/F: nominal `X273 / Y0`;
- service thread candidate: **M8 x 1** internal/female thread;
- protection-cap outside diameter: **<=12 mm**;
- protection-cap exposed height in driving condition: **<=1.5 mm target**, hard screen <=2.0 mm;
- cap head should be flat/rounded and snag-resistant;
- cap may contain a small dirt/water O-ring but must not be the sole pressure-retaining element.

M8 x 1 is chosen provisionally because it is compact, metrically machinable and leaves room inside the WB23E 86 x 44 x 6 cover. Final thread may reopen after prototype adapter testing.

### Internal valve envelope

Reserve below the top port:

- valve/check envelope OD <=10 mm;
- depth below service-cover top <=18 mm nominal;
- lower retainer/service features remain inside the dry service cavity;
- no part of the internal valve is allowed to reduce the main electronics service opening below practical connector access.

A separate dry six-way Micro-Fit connector is kept toward the opposite side of the 48 x 22 service opening.

## 5. Prototype A — source-inspired guided check valve

This is the preferred first machined experiment because it follows the proven source topology without pretending to know proprietary dimensions.

Elements:

- 1 x stainless 4.0 mm precision ball;
- 1 x replaceable soft FKM seat around the gas orifice;
- 1 x short guided valve/push shaft, approximately 3 mm class;
- 2 x 3 x 1 mm FKM O-rings on/around the guided shaft as secondary sealing/guiding elements;
- 1 x small compression spring, source envelope near `d0.5 / De3.7 / L0 7.9` as a starting geometry only;
- 1 x lower perforated spring retainer;
- M8 x 1 top service thread;
- low-profile protection cap;
- screw-on fill/purge adaptor.

Primary closing action:

- spring closes the check element when unpressurised;
- positive internal crawler pressure assists closing/seating;
- the pressure adaptor mechanically pushes the guided element open while screwed in, so opening does not depend on a narrow differential-pressure window;
- after adaptor removal the valve closes before the protection cap is refitted.

This is deliberately simple and avoids a permanently projecting valve stem.

## 6. Prototype B — simplified ball check

Build one comparison insert without the guided shaft/dynamic shaft O-rings:

- 4 mm ball;
- replaceable soft seat;
- small spring;
- lower retainer;
- same M8 x 1 cap/adaptor interface.

The adaptor probe acts directly on the ball/check element.

Purpose of B:

- determine whether the guided shaft is actually necessary;
- reduce moving seals and manufactured parts if the simpler insert leaks less and survives contamination better.

Do not choose A merely because MiniCam used a shaft; choose the simpler design if testing proves it equal or better.

## 7. Protection cap and pressure adaptor

### Driving cap

Target:

- OD <=12 mm;
- exposed height <=1.5 mm preferred;
- M8 x 1 male thread matching service port;
- broad shallow slot / 2-hole pin-spanner / internal hex only if it remains mud-cleanable;
- no tall knurling;
- tethering is optional only if it does not create a snag hazard.

### Fill/purge adaptor

Bench/field tool, not carried in pipe:

- M8 x 1 male nose;
- centre probe opens valve mechanically;
- radial/axial gas passage around probe;
- opposite end accepts standard regulated hose/compressor connection;
- integrated small purge screw preferred so crawler pressure can be deliberately reduced before the service cover is opened;
- adapter must never be used without a pressure regulator.

The user's existing compressor gun can be connected through the tool-side adaptor rather than forcing a tire valve stem into the crawler roof.

## 8. Pressure and force design rule

Crawler normal prototype pressure remains approximately +0.25 bar gauge. Direct pneumatic force on a 3–4 mm class valve element is very small. The spring is therefore selected for reliable seating and contamination tolerance, not for resisting a large pressure load.

Do **not** select spring rate from the source spring dimensions alone. Coil count/material/preload of the original are not controlled. Start with low preload and tune on the bench so the screw-in adaptor opens the valve positively while the released adaptor always leaves a leak-free seat.

## 9. DN150 improvement

Replacing the WB23F Ø14 x 6 exposed-envelope screen with a cap <=Ø12 x 1.5...2.0 mm moves the pressure-port external envelope below the current WB23E cover as the limiting top feature.

Expected consequence:

- pressure valve is no longer the ~4.70 mm DN150 bottleneck;
- top package becomes limited by the service-cover/screw geometry, currently ~7 mm class ideal clearance;
- exact result is checked in the WB24A executable CAD screen before release.

## 10. Contamination/service rules

- valve mouth receives a removable protection cap whenever crawler is in service;
- first internal passage must be drain/cleanable after cap removal;
- seat is replaceable from the underside when service cover is removed;
- no threadlocker is allowed where it could enter the valve passage;
- do not use the protection cap to force a leaking internal valve shut;
- if the primary check leaks, replace/repair valve before wet operation.

## 11. Prototype materials

Candidate starting set:

- ball: AISI 316/440C precision 4 mm, corrosion test decides final grade;
- shaft/retainer: 316L stainless or equivalent corrosion-resistant material;
- seat/seals: FKM first wastewater/chemical candidate;
- service cover: existing EN AW-6082-T6 WB23E cover;
- spring: stainless spring wire; source size is only a geometry starting point;
- adaptor: stainless or nickel-plated brass; final material chosen to avoid galling/corrosion with cover thread.

## 12. Qualification sequence

1. machine/print transparent or open bench mock-up first to observe opening stroke;
2. make Prototype A and B inserts;
3. test dry at 0 / +0.25 / +0.5 bar;
4. connect/disconnect pressure adaptor 100 cycles;
5. perform 30 min decay at +0.25 bar without protection cap — primary valve itself must hold;
6. repeat with cap installed;
7. submerged bubble test;
8. contaminate external mouth with water/fine grit, clean normally, retest;
9. verify purge adaptor can reduce pressure to ambient before cover opening;
10. install winning insert in WB23E cover and run physical DN150 jig;
11. only then release thread/seat/groove dimensions.

## 13. Release state

WB24A freezes the **functional architecture**, not final machining dimensions.

The current pressure-valve procurement search for tall commercial Schrader-style bodies is stopped as baseline. A standard recessed commercial valve core may still be kept as a fallback comparison, but the crawler exterior will retain a Proteus-like low-profile capped service port.

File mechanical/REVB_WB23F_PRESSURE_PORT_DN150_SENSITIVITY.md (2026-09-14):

# PX-1 Rev.B WB23F — pressure-port DN150 sensitivity

Date: 2026-09-14
Status: **PACKAGING RULE FROZEN / VALVE ARTICLE PROCUREMENT HOLD**

## Purpose

The pressure/fill valve is the limiting fixed item on the current WB23E top service cover when the crawler is in LOW and must pass an ideal DN150 cylinder.

WB23F therefore controls the valve procurement envelope before an exact article is selected.

## Current position

- service-cover baseline: WB23E, 86 x 44 x 6 mm;
- nominal pressure-port centre: X273 / Y0;
- only LOW must fit DN150;
- current conservative reference envelope: Ø14 x 6 mm exposed above the cover;
- that envelope leaves about 4.70 mm ideal-DN150 clearance.

## Sensitivity screen

Approximate ideal-DN150 clearance at the current port centre:

| Exposed hard envelope | Ideal DN150 clearance |
|---|---:|
| Ø10 x 5 mm | ~5.87 mm |
| Ø12 x 5 mm | ~5.79 mm |
| Ø14 x 5 mm | ~5.69 mm |
| Ø12 x 6 mm | ~4.79 mm |
| Ø14 x 6 mm | ~4.70 mm |
| Ø14 x 7 mm | ~3.70 mm |
| Ø14 x 7.5 mm | ~3.21 mm |
| Ø14 x 8 mm | ~2.71 mm — FAIL current 3 mm screen |

## Procurement rule

Preferred valve/cap exposed envelope:

**<= Ø12 x 5 mm** above the service-cover outer face.

Acceptable prototype envelope after exact CAD re-check:

**<= Ø14 x 6 mm**.

Do not buy a valve/cap combination taller than about 7.5 mm as a baseline part. Ø14 x 8 mm already fails the current 3 mm ideal-DN150 packaging screen at the present position.

The protective cap counts in the hard envelope. A small valve with a tall cap is not acceptable merely because the bare valve body fits.

## Preferred construction

Prefer, in order:

1. recessed or semi-recessed fill valve with a compact removable cap;
2. low-profile threaded service valve contained largely inside the 6 mm cover/boss geometry;
3. only if necessary, move/reprofile the local service-cover boss after a full WB25 integration check.

Do not enlarge the whole crawler body to accommodate a convenient valve.

## Release gates

Before freezing the pressure-port machining drawing:

- obtain 2–3 real valve candidates;
- measure body OD, exposed height, cap OD/height and required tool clearance;
- verify thread and sealing method;
- update the CAD with the actual solid envelope;
- perform physical DN150 jig check;
- perform +0.25 bar pressure-decay and submerged leak test;
- repeat after valve open/close/service cycles.

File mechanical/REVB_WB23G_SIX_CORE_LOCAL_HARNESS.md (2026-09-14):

# PX-1 Rev.B WB23G — six-core local camera/lift harness correction

Date: 2026-09-14
Status: **PASS_SIX_CORE_PACKAGING_SCREEN / SEAL_TEST_HOLD / FLEX_TEST_HOLD / CABLE_SAMPLE_HOLD / PROCUREMENT_HOLD**

## Correction

The local wet lift/camera harness is **six insulated conductors**, not eight.

Controlled functions are one conductor each:

1. `+12V_HEAD`
2. `GND_HEAD`
3. `UART_TX`
4. `UART_RX`
5. `CVBS_SIGNAL`
6. `CVBS_RETURN`

An overall braid/shield may be present for EMC, but it is not counted as a seventh circuit and is never used as DC power return.

The previous idea of two parallel +12 V conductors and two parallel GND conductors is superseded. It added cable diameter, splice points and service complexity without a demonstrated need on the short local lift harness.

## Cable target

- exactly 6 insulated cores;
- target conductor section: `0.25 mm²` class;
- preferred finished OD: `5.5...6.0 mm`;
- hard packaging maximum: `6.5 mm` because the current SP13 S6I plug is a 4.0...6.5 mm cable class and the M12 gland candidate is 3.5...7 mm;
- overall shield preferred for the mixed CVBS/UART/power environment;
- no loose individual wires across the wet lift.

A current size/electrical benchmark is LAPP `UNITRONIC LiYCY 0034406`, 6 x 0.25 mm², shielded, nominal OD 6.0 mm. It is **not released as the final flex cable** because its published application includes fixed installation/occasional flexing rather than a guaranteed lifetime for the PX-1 lift route. It may be bought only as a prototype/sample benchmark and must pass PX-1 flex/wet/grit testing.

## Dry service disconnect

The previous JST VH 8-way candidate is superseded for this local interface.

Reason: JST VH is a useful power family but its normal published conductor range starts around 0.33 mm²; the current local cable target is 0.25 mm².

Prototype dry wire-to-wire candidate:

- receptacle housing: Molex Micro-Fit 3.0 `43025-0600`, 6 circuits;
- plug housing: Molex Micro-Fit 3.0 `43020-0601`, 6 circuits, no panel ears;
- female crimp contact candidate: `43030-0007`, 20/22/24 AWG class;
- male contact: corresponding `43031` family, exact bag/reel article held until the real cable conductor and insulation OD are measured.

This connector is inside the dry pressure body. It is not a pressure seal and does not replace the M12 gland.

## Camera quick disconnect

WB15 remains unchanged:

- sealed camera panel: WEIPU `SP1312/P6-C`, male pins;
- powered lift harness: WEIPU `SP1310/S6I-N`, female sockets;
- six functions map 1:1 through the local cable.

Numeric pin numbers remain HOLD until physical connectors are inspected from the correct mating/front/rear view.

## Mechanical re-screen

WB23G retains:

- WB22A lift geometry and body pivot X200;
- WB23E service cover 86 x 44 x 6 mm;
- WB23E 48 x 22 mm service opening;
- all 6 wheels and all 10 Z50 gears.

To accommodate a real 6 x 0.25 mm² cable, the local cable hard envelope is increased from 5.0 to 6.5 mm and the conservative removable arm-guard envelope from 7 to 10 mm.

Executed CadQuery result:

- fixed package vs all ten Z50: `0 mm³`;
- fixed package vs all six wheel envelopes: `0 mm³`;
- fixed package vs lift arms: `0 mm³` unintended collision;
- fixed package vs camera: `0 mm³`;
- 10 mm guard vs Z50: `0 mm³`;
- 10 mm guard vs camera: `0 mm³`;
- LOW guard ideal-DN150 clearance: about `27.78 mm`;
- service opening still easily accepts the smaller six-way dry connector envelope.

Only LOW is required to fit DN150; MID/HIGH are lift positions for larger pipes.

## Electrical screen

At the current conservative camera-head peak screen of 2.92 A, 0.25 mm² copper remains reasonable for the short local harness. For a 0.4 m local run the copper-only round-trip screen is about 0.164 V drop at room-temperature resistivity, about 1.36% of 12 V; a +20% resistance screen remains about 1.64%. At 0.6 m the +20% screen is about 2.45%.

These are not cable datasheet guarantees. The purchased cable core resistance must be measured and the real voltage at the head recorded under simultaneous camera, LED and motion load.

## Release gates

1. buy one short sample of candidate six-core cable;
2. measure finished OD and individual conductor copper/insulation dimensions;
3. measure resistance per metre of all six cores;
4. verify the real cable fits both M12 gland and SP13 S6I strain relief;
5. crimp the chosen Micro-Fit contacts and perform pull test;
6. run >=500 LOW-HIGH-LOW cycles, target 1000;
7. repeat after wet/grit exposure;
8. inspect jacket, continuity and shield;
9. run raw CVBS + UART while traction/LED PWM are active;
10. only after this freeze exact cable article and numeric six-pin table.

Controlled files:

- `cadquery/PX1_WB23G_SixCoreHarness_RevB.py`;
- `cadquery/REV_B_WB23G_VALIDATION.json`.

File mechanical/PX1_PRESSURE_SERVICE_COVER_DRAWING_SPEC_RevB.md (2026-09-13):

# PX-1 pressure/camera service cover — drawing specification Rev.B / WB23E screen

Drawing status: **FOR PROTOTYPE LAYOUT ONLY — NOT FOR MACHINING RELEASE**

WB23E supersedes the earlier WB23C/D `78 x 42` cover / `58 x 24` opening layout because the original M4-hole-to-seal-groove web was too small after a realistic face-seal groove was considered.

## Cover plate

- material target: EN AW-6082-T6;
- nominal blank: **86 x 44 x 6 mm**;
- crawler centre: **X261 / Y0**;
- X span: **218...304 mm**;
- datum A: sealing face;
- datum B: long side;
- datum C: cover centreline;
- corner radii: R3 screen, may change with final pressure-roof geometry;
- external edges deburr 0.2–0.5 mm; do not round away the sealing land.

## Opening below cover

Body-opening screen:

- **48 x 22 mm**;
- X range: **237...285 mm**;
- Y range: **-11...+11 mm**;
- centred on cover Y;
- dry JST VH 8-position connector family envelope (~31.62 x 10.5 mm) fits through this opening at screen level.

Do not machine the body opening from this note until real connector/gland/valve samples and the final pressure-body drawing are checked.

## Fasteners

Screen:

- **2 x M4**;
- M4 clearance-hole study diameter: **Ø4.5 mm**;
- screw-head hard-envelope study: **Ø8 mm**;
- X pitch: **70 mm**;
- centres: **X226 and X296**, Y0 in crawler coordinates;
- blind body threads preferred so service does not create another through-pressure path;
- retained/captive screws preferred for field service.

WB23E screen margins:

- minimum M4 clearance-hole edge to provisional seal-groove outer edge: **3.5 mm**;
- minimum Ø8 head-envelope edge to cover end: **4.0 mm**.

Final hole form, counterbore/countersink, screw length, thread engagement and torque depend on the purchased screw and body-boss thickness.

## Face seal

Screen only:

- target elastomer cord: Ø2.0 mm FKM class;
- provisional groove centre-path offset from service-opening edge: **4.0 mm**;
- provisional groove width: **2.5 mm**;
- provisional groove depth: **1.5 mm** only as a packaging study;
- continuous closed groove with generous corner radii;
- no groove break at screws, fill valve or gland;
- minimum provisional groove outer edge to cover Y edge: **5.75 mm**.

**Groove depth/width are not released machining dimensions.** Final values are recalculated from the actual purchased elastomer diameter, hardness, squeeze, gland fill, surface finish and thermal expansion.

## Fill / pressure port

Reserve a local boss around **X273 / Y0**.

Current hard packaging envelope in WB23E remains:

- no more than Ø14 mm;
- no more than 6 mm exposed height in the current screen;
- low-profile compressor-gun / Schrader-compatible or equivalent service interface;
- cap/removal-tool access.

A later pressure-port sensitivity study controls the preferred smaller envelope. Do not drill/thread before the exact valve is selected.

## Cable gland

LAPP `SKINTOP MS-M 53112000` is packaged horizontally in a pressure-pod front/side boss, not standing vertically on the cover.

Reserve:

- M12 x 1.5 thread;
- >=6.5 mm thread-engagement geometry for sample check;
- tool access for 16 mm wrench class;
- external envelope Ø17.6 x 26.5 mm class;
- nominal axis Y+12 / Z103;
- cable exit clear of sharp edges and lift pivot.

## Marking

Laser engraving / durable marking target:

`PRESSURE / CAMERA SERVICE`

Second line:

`DEPRESSURIZE BEFORE OPENING`

## Controlling status

WB23E controls prototype cover/opening/screw geometry. WB23C remains the functional service-topology definition and WB23D remains the first full-body integration proof.

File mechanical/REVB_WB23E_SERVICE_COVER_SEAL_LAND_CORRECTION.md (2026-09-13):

# PX-1 Rev.B — WB23E service-cover seal-land correction

Date: 2026-09-14
Status: **PASS_SEAL_LAND_AND_FULL_INTEGRATION_SCREEN / SEAL_TEST_HOLD / FLEX_TEST_HOLD / PROCUREMENT_HOLD**

## Why WB23E was required

WB23C/D established the correct simple Proteus-style topology, but a detailed fastener/seal review found that the first `78 x 42` cover with `58 x 24` opening placed the M4 clearance-hole centres only 4 mm outside the opening edge. After accounting for a realistic face-seal groove and M4 clearance-hole radius, the remaining web was too small for a sensible prototype.

This is a real design correction, not a cosmetic change.

## Corrected cover screen

WB23E changes only the small service cover/opening package:

- cover centre X: **261 mm**;
- cover: **86 x 44 x 6 mm**;
- cover X span: **218...304 mm**, fully supported by the pressure pod;
- service opening: **48 x 22 mm**;
- opening X span: **237...285 mm**;
- opening Y span: **-11...+11 mm**;
- two M4 centres: **X226 / X296**, Y0;
- pressure-valve screen centre: **X273 / Y0**;
- provisional seal-groove centre offset from opening edge: **4.0 mm**;
- provisional groove width: **2.5 mm**.

WB22A lift geometry, horizontal M12 gland and local harness route are unchanged.

## Seal/fastener geometry result

Using an M4 clearance-hole diameter of 4.5 mm and an 8 mm screw-head envelope:

- minimum clearance-hole edge to provisional groove outer edge: **3.5 mm**;
- minimum screw-head edge to cover outer edge: **4.0 mm**;
- minimum groove outer edge to cover Y edge: **5.75 mm**.

This is significantly more credible than the original WB23C/D land.

The dry JST VH 8-position connector family envelope was also screened at approximately 31.62 x 10.5 mm and fits through the revised 48 x 22 mm service opening.

## Pressure-force screen after smaller opening

Opening area is reduced to 48 x 22 mm:

- +0.25 bar separating force: **26.4 N**;
- +1.0 bar separating force: **105.6 N**;
- ideal equal share at 1 bar: **52.8 N per M4 screw**.

Again, this is only a load-magnitude sanity check, not a plate/thread certification.

## Full integration result retained

The corrected package still passes the complete WB22A integration screen:

- body remains valid after opening cut;
- opening remains inside pressure pod;
- cover remains supported by pressure pod;
- horizontal gland crosses pod front wall as intended;
- fixed package vs ten Z50: 0 mm³;
- fixed package vs six wheel envelopes: 0 mm³;
- fixed package vs lift arms LOW/MID/HIGH: 0 mm³;
- fixed package vs camera outer envelope: 0 mm³;
- lift guard vs package/Z50: 0 mm³.

DN150 fixed clearances:

- corrected cover: **~7.37 mm**;
- pressure-port envelope: **~4.70 mm**;
- horizontal M12 gland: **~13.86 mm**;
- M4 heads: **~7.93 mm**.

The pressure port remains the limiting fixed item.

## Control decision

WB23E supersedes the dimensional cover/opening/screw data in WB23C and WB23D. WB23C remains the functional topology definition and WB23D remains the first full-integration proof, but any prototype cover layout after 2026-09-14 uses WB23E dimensions.

Final groove depth/width is still not released until the purchased seal material and compression target are known.

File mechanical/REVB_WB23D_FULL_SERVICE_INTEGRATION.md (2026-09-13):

# PX-1 Rev.B — WB23D full pressure-service integration screen

Date: 2026-09-14
Status: **PASS_FULL_INTEGRATION_SCREEN / SEAL_TEST_HOLD / FLEX_TEST_HOLD / PROCUREMENT_HOLD**

## Purpose

WB23C proved the pressure/service concept using a local pressure-roof reference. WB23D reinserts the same package into the exact corrected WB22A body geometry and checks it against the hard six-wheel crawler, all ten Z50 gears, lift arms and camera envelope.

No WB22A hard geometry is changed.

## Body integration

The service opening is cut through the WB22A pressure pod at:

- X = 228...286 mm;
- Y = -12...+12 mm;
- opening size = 58 x 24 mm.

Checks:

- opening lies inside the pressure-pod plan envelope: PASS;
- corrected WB22A body remains a valid solid after opening cut: PASS;
- M12 gland axis crosses the pressure-pod front wall as intended: PASS.

## Architecture lock

Executable model explicitly contains:

- 6 wheels;
- X50 / X150 / X250 wheel stations;
- 10 Z50 side gears;
- body lift pivot X200.

No four-wheel/two-axle interpretation is introduced.

## Fixed package DN150 screen

- cover: ~7.688 mm;
- pressure port hard envelope: ~4.699 mm;
- horizontal M12 gland: ~13.855 mm;
- M4 head 1: ~7.929 mm;
- M4 head 2: ~7.929 mm.

The fill/pressure port remains the limiting fixed feature.

## Full collision result

Across LOW / MID / HIGH checked lift states:

- fixed service package vs all ten Z50: 0 mm³;
- fixed package vs all six wheel envelopes: 0 mm³;
- fixed package vs four lift arms: 0 mm³;
- fixed package vs conservative camera outer envelope: 0 mm³;
- protected local harness guard vs fixed service package: 0 mm³;
- guard vs all Z50: 0 mm³.

LOW guard ideal-DN150 clearance remains ~29.234 mm.

MID and HIGH are not DN150-required positions; HIGH leaving DN150 is expected and is not a failure.

## Pressure-load sanity screen

For the 58 x 24 mm opening:

- +0.25 bar: ~34.8 N separating force;
- +1.0 bar: ~139.2 N total;
- ideal equal share on two screws at 1 bar: ~69.6 N each.

This is not a cover-stress or thread-certification calculation. It only confirms that pressure force magnitude itself does not justify a bulky multi-bolt cover. Sealing, plate stiffness, impact, gasket compression and thread engagement remain physical gates.

## Result

WB23D confirms that the simple Proteus-style service topology is compatible with the corrected WB22A crawler geometry. The project should **not** return to the abandoned dual-flex-chamber solution unless physical tests prove the simple topology inadequate.

## Remaining release gates

- real LAPP gland sample;
- real <=5 mm cable sample;
- real low-profile pressure valve;
- final body boss and O-ring groove design;
- +0.25 bar pressure decay and submersion;
- lift endurance and wet/grit cycling;
- physical DN150 jig with final hardware;
- full manufacturing tolerance review.

Controlled files:

- `cadquery/PX1_WB23D_FullServiceIntegration_RevB.py`;
- `cadquery/REV_B_WB23D_VALIDATION.json`;
- WB23C remains the functional/service definition.

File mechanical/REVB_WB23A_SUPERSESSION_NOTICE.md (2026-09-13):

# Rev.B WB23A routing supersession notice

Date: 2026-09-14

WB23A remains useful evidence that a thin local harness and guard can fit the lower lift arm. It is **not** the controlling camera-lift routing release after WB23C.

Two reasons:

1. WB23A's one-sided `Workplane('XZ')` helper introduced a Y-direction/sign ambiguity for asymmetric cover geometry. Symmetric lift-arm checks were not materially affected, but absolute one-sided Y placement must not be used as manufacturing data.
2. WB23B then overextended the study into dedicated radius-controlled flex chambers. Repair photographs and MiniCam source drawings support a simpler removable pressure-cover + M12 gland + protected short harness topology.

Controlling interpretation after this notice:

- hard lift/camera geometry: **WB22A**;
- pressure/service cover and local harness topology: **WB23C**;
- camera quick connector: **WB15**;
- WB23A: historical static-packaging study only.

Do not use WB23A clamp coordinates, its sign-sensitive absolute Y construction, or the abandoned WB23B flex-fan concept in machining drawings.

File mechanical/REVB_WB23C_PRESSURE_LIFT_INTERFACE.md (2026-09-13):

# PX-1 Rev.B — WB23C Proteus-style pressure/service cover and camera-lift harness

Date: 2026-09-14
Status: **PASS_PACKAGING_SCREEN / SEAL_TEST_HOLD / FLEX_TEST_HOLD / PROCUREMENT_HOLD**

## 1. Purpose and correction

WB23A proved that a thin protected local harness can fit the lift, but the following WB23B study started to over-engineer cable motion with two dedicated flex chambers and imposed-radius loops. Repair evidence and MiniCam source drawings show a simpler, more serviceable topology.

WB23C therefore supersedes the WB23B flex-fan / dual-flex-chamber direction and returns to the source architecture:

`dry crawler body -> removable sealed service cover -> pressure valve + cable gland -> short flexible harness -> protected lift run -> fixed camera connector -> sealed removable camera`.

No crawler axle, wheel, Z50 gear, lift pivot or camera geometry is changed by WB23C.

## 2. Proteus source basis

The source package controls topology, not PX-1 manufacturing dimensions:

- `DRW-002-752 LIFT HOUSING`: camera connector, connector housing, M12x1.5 cable fitting for 3.5–5 mm cable, lift cover and multiple O-rings.
- `DRW-002-745 Crawler Cover Parts`: M12x1.5 cable fitting, holder, spring-loaded camera/pressure-valve components and electronic cover.
- `ASS-002-890 LIFT HOUSING UNIT - CRP300`: lift housing, lift-housing cover, M12 gland, camera connector and protection sheet.
- `DRW-003-121 / ASS-003-121`: dedicated `CAMERA LIFT ARM COVER`, side arms and lift-housing holding plates.
- repair-photo set 2025-03-14: integrated pressure body, serviceable upper/lift opening, perimeter seal land, camera connector and open dry electronics.

The current evidence does **not** conclusively prove that the exact CRP150 small cover marked `PRESSURE` is held by exactly two bolts. PX-1 uses two M4 screws as an independent compact-service-cover design choice, subject to prototype sealing and stiffness tests.

## 3. WB22A architecture retained

- 3 wheel stations per side / 6 wheels total.
- X50 / X150 / X250 wheel stations.
- ten m1 Z50 side gears total.
- rear X250 drive input.
- body pivot X = 200 mm.
- lift pivots Z = 92 / 109 mm.
- four-bar link = 90 mm.
- arm planes Y = ±31 mm, screen section 4 x 14 mm.
- sealed camera shell Ø52 x 78 mm.
- LOW optical axis X = 83.5569 mm, Z = 75 mm.

WB23C explicitly rejects the earlier trial move to X207.5.

## 4. PX-1 pressure/camera service cover

Packaging-screen cover:

- material target: EN AW-6082-T6 aluminium;
- outer envelope: **78 x 42 x 6 mm**;
- centre: X257 / Y0;
- service opening below cover: **58 x 24 mm**;
- target seal cord: 2.0 mm;
- provisional face-groove study: 2.5 mm wide x 1.5 mm deep;
- fasteners: **2 x M4 A4 stainless** into blind body threads/bosses;
- screen screw X positions: X224 and X290, Y0;
- marking: `PRESSURE / CAMERA SERVICE`.

The groove dimensions are **not machining-release dimensions**. Final gland, seal material/hardness, surface finish and measured flatness control the released drawing.

### Pressure-force sanity check

The 58 x 24 mm opening area gives approximately:

- 34.8 N separating force at +0.25 bar gauge;
- 139.2 N at +1.0 bar gauge;
- 69.6 N per screw at +1.0 bar if shared equally.

Fastener tensile capacity is therefore not the primary concern. Plate bending, gasket compression uniformity, thread engagement, impact and sealing remain physical-test gates.

## 5. Pressure fill point

Proteus source architecture uses a compact spring-loaded pressure-valve concept. PX-1 retains that service intent without copying an unavailable proprietary part.

Current packaging envelope:

- exposed OD <= 14 mm;
- exposed height above cover <= 6 mm;
- screen centre X268 / Y0;
- candidate thread class M10x1 or G1/8;
- compressor-gun / Schrader-compatible or equivalent industrial fill interface;
- metal protective cap or recessed protection required.

Exact valve article remains **PROCUREMENT HOLD**. The valve is the limiting fixed DN150 item in the current screen at about **4.70 mm** ideal clearance, so its height must not grow casually.

## 6. Cable gland

Controlled candidate:

- LAPP `SKINTOP MS-M 53112000`;
- M12 x 1.5;
- cable range 3.5–7.0 mm;
- hard body OD screen 17.6 mm;
- overall length screen 26.5 mm;
- thread length screen 6.5 mm.

WB23C places the gland **horizontally / forward-facing**, approximately X218.25, Y+12, Z103. A vertical gland consumes excessive DN150 roof clearance. The horizontal envelope leaves about 13.86 mm ideal-DN150 clearance.

The gland is a pressure-boundary cable seal, **not an electrical connector**.

## 7. Local camera/lift harness

Target OD: **<= 5.0 mm**.

Preferred content:

1. +12V_HEAD A
2. +12V_HEAD B
3. GND_HEAD A
4. GND_HEAD B
5. HEAD_UART_TX
6. HEAD_UART_RX
7. CVBS_SIGNAL
8. CVBS_RETURN
9. overall shield if available — EMC only, never DC return.

Protected lower-arm run:

- cable centre Y target +25.5 mm;
- screen arm-coordinate protected region s ≈ 20...72 mm;
- simple removable anti-snag cover over the straight run;
- no artificial constant-radius loop frozen in CAD.

Service slack targets are about 35 mm body-side and 35 mm head-side. Real bend shape is established on the physical lift with the selected cable.

## 8. Internal dry connector

Prototype candidate:

- JST `B8P-VH-B` 8-position header;
- JST `VHR-8N` housing;
- contacts selected for the purchased conductor cross-section.

Purpose: the external cover/gland/lift-harness assembly can be disconnected inside the dry body without unsoldering or removing the main electronics.

Rules:

- keyed/polarized orientation;
- separate strain relief before connector;
- connector does not support gland cable mechanically;
- label `J_CAM_LIFT`;
- contact numbering frozen only after the real pair is in hand.

## 9. Camera connector

WB15 remains controlling:

- camera panel: WEIPU `SP1312/P6-C`, male pins;
- powered harness: WEIPU `SP1310/S6I-N`, female sockets, if final cable OD is within its 4.0–6.5 mm range;
- six functions: +12V, GND, UART TX, UART RX, CVBS signal, CVBS return.

If purchased cable OD falls outside the S6I range, the plug size is reselected before procurement without changing the six-function interface.

## 10. Executed DN150 packaging result

CadQuery WB23C result:

- service cover: ~7.69 mm clearance;
- low-profile fill-valve envelope: ~4.70 mm;
- horizontal M12 gland: ~13.86 mm;
- two M4 head envelopes: ~7.93 mm;
- protected local cable / guard in LOW: ~30.20 / 29.23 mm.

MID and HIGH lift positions are not required to remain inside DN150 because they are larger-pipe operating positions. DN150 release is controlled in LOW, consistent with WB22A.

## 11. Field-service concept

1. Power crawler off.
2. Fully depressurize.
3. Clean and dry service area.
4. Disconnect camera SP13.
5. Remove two retained M4 service-cover screws.
6. Lift cover with gland/harness still attached.
7. Disconnect `J_CAM_LIFT` inside dry body.
8. Withdraw cover/gland/harness as one service assembly.
9. Inspect/replace seal.
10. Install replacement assembly.
11. Run pressure-decay and submerged leak test before wet use.

The main electronic stack should not need removal for a damaged camera-lift harness.

## 12. Release gates

WB23C is not manufacturing/procurement release until:

1. exact M12 gland is purchased/measured;
2. <=5 mm 8-core + shield cable is selected/purchased;
3. low-profile fill valve is selected/purchased;
4. SP13 and dry connector samples are measured;
5. service-cover prototype proves access/alignment;
6. +0.25 bar dry pressure-decay passes;
7. submerged leak test passes;
8. if final crawler keeps a 1 bar rating, controlled 1 bar proof passes;
9. LOW-HIGH-LOW lift cycling >=500, target 1000 cycles, passes;
10. wet/grit cycling passes;
11. conductor resistance, shield continuity, UART and CVBS remain healthy;
12. O-ring groove and cover torque are frozen from real parts and flatness;
13. final fastener heads, valve, gland and real wheel solids are checked in the full master.

## 13. Change log

### 2026-09-14 — WB23C

- stopped unnecessary WB23B R16 flex-fan / dual-flex-chamber work;
- retained WB22A X200 mechanics unchanged;
- returned harness topology to verified Proteus service logic;
- introduced compact `PRESSURE / CAMERA SERVICE` cover;
- chose two M4 screws as PX-1 prototype geometry without claiming exact original Proteus count;
- retained source-like M12 gland class and oriented it horizontally for DN150;
- separated cable pressure seal from dry electrical disconnect;
- froze <=5 mm local harness target and simple protected lower-arm run;
- retained WB15 SP13 camera quick-disconnect;
- executed DN150 packaging screen and obtained PASS;
- seal, flex-life and procurement remain explicit HOLDs.

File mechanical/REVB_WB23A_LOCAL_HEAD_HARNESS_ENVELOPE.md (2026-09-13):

# PX-1 Rev.B — WB23A local head harness envelope

Date: 2026-09-13  
Status: **PASS_STATIC_PACKAGING / FLEX TEST HOLD / MANUFACTURING HOLD / PROCUREMENT HOLD**

## Scope

WB23A re-solves the local camera harness after WB22A corrected the lift geometry. WB21 clamp coordinates and the 52.8 mm free-flex length are therefore superseded mechanically.

WB22A hard geometry remains unchanged:
- 3 axles / 6 wheels;
- X50 / X150 / X250;
- ten Z50 side gears;
- body pivot X200;
- lift pivots Z92/Z109;
- link length 90 mm;
- arm planes Y=±31 mm;
- arm section 4 x 14 mm.

## Source-derived topology

MiniCam source drawings show a smaller local cable class and a protected lift-arm route:
- `CAB-002-461` is an M12x1.5 cable fitting for approximately 3.5...5 mm cable in `DRW-002-752`, `DRW-002-745` and `ASS-002-890`;
- `FSS-003-127 LIFT ARM COVER` is present in `ASS-003-121` / `DRW-003-121`.

Repair photographs are used only as topology evidence. No PX-1 dimensions are scaled from photos.

## Controlled PX-1 static run

The prototype local-harness envelope is reduced to **<=5.0 mm OD** and routed on the inner side of the +Y lower lift arm.

Controlled geometry:
- cable centre Y = 25.5 mm;
- 25 mm setback from each pivot reserved for future flex zones;
- protected static middle run = 40 mm;
- protective cover screen = 7 mm Y thickness x 7 mm XZ height;
- nominal cover wall target = 1 mm.

This removes the need to move the validated WB22A body pivot from X200 merely to package the old Ø8 WB21 cable.

## Executed validation

Executable CAD:
`mechanical/cadquery/PX1_WB23A_LocalHarnessEnvelope_RevB.py`

Executed result:
`mechanical/cadquery/REV_B_WB23A_VALIDATION.json`

The full lift was sampled at 43 solid states from -17.7916° to +66.4435°. Results:
- cable vs body: 0 mm³;
- cable vs ten Z50: 0 mm³;
- cable vs four arms: 0 mm³;
- cable vs carrier at LOW/MID/HIGH: 0 mm³;
- cover vs body/Z50/arms/carrier: 0 mm³;
- minimum cable-to-wet-floor clearance: 24.565 mm;
- minimum cover-to-wet-floor clearance: 24.765 mm.

A separate 1001-position lift check against the conservative complete TILT swept envelope gives:
- minimum cable margin: 3.319 mm;
- minimum cover margin: 2.319 mm.

The critical static-run condition is HIGH, with camera axis approximately X133.284 / Z185 mm.

## DN150 LOW

At LOW:
- static cable start ≈ X176.196 / Y25.5 / Z84.361 mm;
- static cable end ≈ X138.109 / Y25.5 / Z72.139 mm;
- ideal-DN150 cable clearance ≈ 31.410 mm;
- ideal-DN150 cover clearance ≈ 29.744 mm.

Therefore this static harness section is not the DN150 limiting hard part. The moving TILT head remains the limiting WB22A geometry.

## Electrical/procurement candidates

Electrical allocation remains eight insulated conductors:
- two parallel +12 V;
- two parallel GND;
- UART TX/RX;
- CVBS signal/return;
- shield used only for EMC, never DC return.

Body gland candidate: `LAPP SKINTOP MS-M M12x1.5 53112000`, 3.5...7 mm cable class. It is not pressure released.

Prototype donor-cable candidate: `Autonics CID9S-2`, approximately Ø5 mm, eight insulated conductors plus shield. No accepted continuous-flex life/radius data has been frozen, so it remains a test-gated prototype candidate.

## Open gates

WB23A does not release the complete harness. Remaining work:
1. body-side pivot flex zone;
2. carrier-side pivot flex zone and transition to the fixed camera connector;
3. purchased-cable OD/resistance/flex qualification;
4. wet/grit lift-cycle test;
5. cover drainage, fasteners and anti-snag details;
6. M12 pressure boss and +0.25 bar leak proof;
7. CVBS interference test with TILT/ROLL motors and LED PWM.

Next controlled block: **WB23B — pivot flex zones and final head-connector transition.**

## Change log

### 2026-09-13 — WB23A
- retained WB22A lift geometry and six-wheel hard lock;
- replaced the obsolete WB21 Ø8 local packaging assumption with a <=Ø5 protected local-harness envelope;
- reserved two 25 mm flex zones and validated the 40 mm protected static run;
- retained FLEX/PROCUREMENT/MANUFACTURING holds until physical cycling and pressure tests are complete.

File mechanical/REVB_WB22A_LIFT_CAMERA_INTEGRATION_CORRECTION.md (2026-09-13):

# PX-1 Rev.B — WB22A lift/camera integration correction

Date: 2026-09-13  
Status: **PASS_SCREEN / MANUFACTURING HOLD / PROCUREMENT HOLD**

## 1. Why WB22A exists

WB22A is a corrective work block inserted before the previously planned static head-harness work.

Two integration faults were found while auditing WB20/WB21 against the controlled CRP-150 drawings and the user's 2025-03-14 Proteus service photographs:

1. one WB20 audit model extruded the wet-bay cut in the wrong `Y` direction; the intended `-38...+38 mm` open wet channel was therefore not represented by that audit solid;
2. WB21 placed the four-bar end pivots effectively on the camera TILT axis. Exact solid intersection checks then showed the lift plates occupying the same volume as the moving camera package.

The service photographs show the useful source topology more clearly: the lift linkage terminates in a separate rigid head-support structure and the camera is mounted ahead of that structure. The photographs are used only as topology/packaging evidence; no dimension has been scaled from a photograph.

WB22A therefore changes the active sequence to:

`pressure body -> four-bar lift -> fixed head carrier -> sealed TILT camera`.

This correction supersedes the WB20/WB21 lift geometry wherever they conflict. It does **not** change the hard crawler architecture.

## 2. Architecture retained

Unchanged Rev.B locks:

- 3 wheel stations per side / 6 wheels total;
- wheel stations `X50 / X150 / X250`;
- 100 mm station pitch / 200 mm front-to-rear wheelbase;
- five module-1 Z50 gears per side / ten total;
- two traction motors total;
- rear `X250` input on each side;
- dry pressurised body;
- manual camera lift;
- sealed Ø52 camera package;
- no mechanical cartridges/cassettes.

## 3. Corrected wet bay

The WB20 profile is retained:

- floor/pressure-roof outer profile points: `(X0,Z22)`, `(140,26)`, `(200,77)`, `(220,90)`;
- wet-bay half width: `38 mm`;
- nominal pressure-roof thickness: `5 mm`.

CadQuery `XZ` positive extrusion runs toward `-Y`. WB22A therefore starts the wet cut at `Y=+38 mm` and extrudes 76 mm. An explicit assertion now requires:

- wet cut `Ymin = -38.000 mm`;
- wet cut `Ymax = +38.000 mm`.

This prevents the previous sign error from silently returning.

## 4. Corrected lift geometry

Controlled WB22A values:

- body pivot X: **200.0 mm**;
- lower body pivot Z: **92.0 mm**;
- upper body pivot Z: **109.0 mm**;
- pivot separation: **17.0 mm**;
- link length: **90.0 mm**;
- arm centre planes: **Y = ±31.0 mm**;
- arm plate section: **4.0 x 14.0 mm**;
- vertical edge gap between lower/upper plates at the pivots: **3.0 mm**.

The arm section is an engineering screen, not a released material/thickness decision. Final material, fatigue, buckling and abuse-load checks remain on HOLD.

### Why the WB21 120 mm links were not retained

With WB21's end pivot at the TILT axis, the four plates physically intersect the camera. Merely moving the plates sideways forced them into the yoke/Z50 corridor and left poor dirty-service margins.

WB22A instead uses a shorter 90 mm parallelogram and places a rigid carrier between the lift and camera. This preserves the LOW optical-axis position without moving the Z50 side gear planes.

## 5. Fixed head carrier

The carrier is rigid with the four-bar and does not TILT with the camera.

Derived carrier offset from the lift end pivot to camera axis:

- **30.7474 mm forward in X**.

This value is derived so the WB20 LOW camera axis remains exactly:

- `X = 83.5569 mm`;
- `Z = 75.0000 mm`.

Carrier screen:

- side cheek inner face: `|Y| = 35.0 mm`;
- side cheek outer face: `|Y| = 37.5 mm`;
- side cheek thickness: `2.5 mm`;
- pivot pin diameter screen: `8 mm`;
- rear/upper cross tie relative to camera axis: `+48 mm X / +30 mm Z`;
- cross-tie envelope: `8 x 75 x 5 mm`.

The carrier side structure remains outside the moving head. The cross tie is positioned outside the complete radial envelope of the TILT package.

Calculated cross-tie margin to the full moving radial envelope:

- **5.0147 mm**.

## 6. LOW/MID/HIGH kinematics

### LOW

- lift angle: `-17.7916 deg`;
- camera axis: `X83.5569 / Z75.0000 mm`;
- lift-end pivots: `X114.3043 / Z64.5` and `X114.3043 / Z81.5 mm`.

### MID

- lift angle: `+17.7916 deg`;
- camera axis: `X83.5569 / Z130.0000 mm`;
- lift-end pivots: `X114.3043 / Z119.5` and `X114.3043 / Z136.5 mm`.

### HIGH

- lift angle: `+66.4435 deg`;
- camera axis: `X133.2838 / Z185.0000 mm`;
- lift-end pivots: `X164.0313 / Z174.5` and `X164.0313 / Z191.5 mm`.

HIGH is a large-pipe/service position and is not a DN150 operating position.

## 7. Executed solid collision checks

CadQuery 2.8.0 was executed against:

- corrected body/wet-bay solid;
- all four lift arms;
- fixed carrier;
- all ten Z50 solids;
- Ø52 x 78 mm moving camera package;
- TILT package from `-105...+105 deg` in 1-degree steps for pipe/floor sweep;
- one 150 N gas spring envelope.

For LOW, MID and HIGH:

- lift arms vs body: **0 mm3**;
- lift arms vs all Z50: **0 mm3**;
- lift arms vs fixed carrier structure: **0 mm3**;
- carrier vs body: **0 mm3**;
- carrier vs all Z50: **0 mm3**;
- gas spring vs body: **0 mm3**;
- gas spring vs Z50: **0 mm3**;
- gas spring vs carrier: **0 mm3**;
- gas spring vs lift arms: **0 mm3**.

All-angle moving-head separation is additionally controlled by invariant envelopes about the TILT Y axis:

- arm-to-shell lateral gap: **3.00 mm**;
- negative-side arm to TILT-pod lateral gap: **3.25 mm**;
- minimum arm-end radial gap to TILT boss: **14.43 mm**;
- carrier inner face to camera boss: **1.00 mm**.

The 1.00 mm boss/carrier value is acceptable only for the current CAD screen; manufacturing tolerance, grit and axial play must be resolved before release.

## 8. DN150 LOW gate

Ideal DN150 screen at LOW:

- moving camera minimum clearance over the full 1-degree TILT sweep: **3.0405 mm** at about `-61 deg`;
- moving camera minimum wet-floor clearance: **3.7214 mm** at about `-58 deg`;
- lift-arm minimum ideal-pipe clearance: **4.9300 mm**;
- fixed carrier minimum ideal-pipe clearance: **8.0585 mm**;
- gas spring minimum ideal-pipe clearance: **37.17 mm**.

These are ideal-cylinder CAD values, not dirty/oval-pipe release values. The moving camera remains the DN150 limiting hard part.

## 9. Gas spring

The MiniCam source package confirms the use of one **150 N gas spring** in the manual lift (`DRW-002-744`). WB22A keeps that source principle.

Current prototype candidate retained for packaging screen:

- ACE `GS-12-20-V4A`;
- force screen: `150 N`;
- body OD screen: `12 mm`;
- stroke: `20 mm`;
- nominal extended length screen: `72 mm`;
- nominal retracted length screen: `52 mm`.

WB22A geometry:

- fixed base: `X195.0 / Y0 / Z84.0 mm`;
- moving attachment: `62.5 mm` from the lower body pivot.

Calculated spring lengths:

- LOW: **55.629 mm**;
- MID: **60.874 mm**;
- HIGH: **68.280 mm**.

Minimum margin from either stroke end: **3.629 mm**.

Assist torque at 150 N:

- LOW: **1.026 N m**;
- MID: **1.408 N m**;
- HIGH: **1.068 N m**.

This proves geometry, not final hand force. Final camera/carrier mass and CG are still required before the spring force is released.

## 10. Effect on WB21 harness

WB21's cable article, electrical allocation and body-gland study remain useful technical work, but its lift-arm coordinates are no longer controlling because WB22A changes:

- link length;
- upper pivot height;
- arm Y plane;
- arm section;
- camera-to-link interface;
- moving carrier geometry.

Therefore the WB21 `52.8 ±0.5 mm` flex length and `Y=-13` moving-clamp solution must **not** be released or manufactured from the old coordinates.

The next harness work is renumbered **WB23** and must be re-solved on WB22A geometry.

## 11. Remaining HOLDs

Before manufacturing release:

1. assign final material to the 4 x 14 mm lift arms and run bending/fatigue/abuse-load calculations;
2. dimension real pivot bushes, washers, circlips and axial float using purchasable parts;
3. increase or tolerance-control the 1.0 mm carrier-to-camera-boss lateral gap;
4. add dirt relief/drainage and anti-snag radii to the carrier webs;
5. calculate carrier stiffness with camera mass and cable pull;
6. verify the physical gas-spring article and end fittings from an allowed procurement source;
7. weigh the actual camera/carrier and tune spring force for one-hand operation;
8. run a printed/metal LOW jig in a real DN150 pipe, including ovality, grit and cable drag;
9. re-solve the complete body-to-camera harness on WB22A geometry;
10. do not machine from this work block yet.

## 12. Next work block

**WB23 — corrected lift harness and final serviceable head connector.**

WB23 must:

- retain a serviceable straight six-contact SP13-class connector unless a better field-repairable part is proven;
- route the local head cable on the corrected 90 mm lift;
- define both body-pivot flex and camera-carrier transition explicitly;
- avoid a hidden second uncontrolled flex zone;
- retain field camera replacement without opening the pressurised crawler body;
- re-check all LOW/MID/HIGH collisions against all ten Z50 and the gas spring.

## Change log

### 2026-09-13 — WB22A

- audited the user's Proteus repair photographs against the source drawings;
- recorded photographs as topology evidence only;
- found and corrected the WB20 wet-cut extrusion-direction mistake;
- found the previously missed WB21 four-bar/camera solid collision;
- rejected the attempted cure of simply pushing the arms out toward the Z50 gears;
- introduced a rigid head carrier between four-bar and sealed camera;
- changed lift link length from 120 to 90 mm;
- changed upper body pivot from Z112 to Z109 mm;
- selected a screened 4 x 14 mm arm section on `Y=±31 mm`;
- preserved the WB20 LOW optical-axis position;
- re-screened all ten Z50, body, carrier, gas spring and DN150;
- achieved `PASS_SCREEN / MANUFACTURING HOLD / PROCUREMENT HOLD`;
- declared WB21 harness coordinates superseded and moved harness work to WB23.

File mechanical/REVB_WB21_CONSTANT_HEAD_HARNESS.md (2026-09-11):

# PX-1 Rev.B — WB21 constant-length local camera harness

Date: 2026-09-11  
Status: **PASS_SCREEN / MANUFACTURING HOLD / PROCUREMENT HOLD**

## 1. Scope

WB21 re-solves the camera-head local harness after the WB20 wet-bay/TILT correction.

The objective is not to find a different shortest cable path for LOW/MID/HIGH. A real harness has one fixed cut length. WB21 therefore creates one controlled flex zone at the lower lift pivot while the rest of the harness is statically supported.

No change is made to:
- 3 axles / 6 wheels;
- X50 / X150 / X250 wheel stations;
- ten Z50 side gears;
- rear X250 drive input;
- manual four-bar lift;
- sealed Ø52 camera/TILT/ROLL architecture;
- six functional head circuits;
- main six-core inspection tether.

## 2. Source-derived principle

The MiniCam source package supports the architecture, not PX-1 dimensions:

- `DRW-002-752 LIFT HOUSING` contains a separate `FSS-002-085 Camera Connector`, `FAL-002-071 Housing Cameraconnector` and `CAB-002-461 cable fitting M12x1.5 d3.5-5mm`;
- `ASS-002-890 Top Housing Assy` independently contains both a camera connector and an M12 gland;
- `ASS-003-121 Lift Arm Assy` contains a dedicated lift-arm cover.

PX-1 interpretation:

`sealed body ingress -> fixed support/fairlead -> one controlled pivot flex -> protected static arm run -> removable head connector`.

This supersedes the WB19 idea of storing a large free loop above the controller saddle.

## 3. Cable selection

Technical baseline candidate:

**igus chainflex CF99.PLUS.01.08**

Controlled manufacturer data used by WB21:
- construction: `(8 x 0.14 mm2)C`;
- shielded;
- TPE jacket;
- outside diameter: 8.0 mm;
- maximum conductor resistance at 20 C: 140 ohm/km;
- catalogue current reference for one 0.14 mm2 conductor: 2.5 A at 30 C, subject to installation/loaded-core derating;
- at -25...+80 C: minimum radius 3xd for 5 million double strokes, 5xd for 40 million, 6xd for 100 million.

WB21 uses **R >= 40 mm = 5xd** as the geometry gate. This is deliberately much more cycle capability than the manual lift requires.

### Important sourcing correction

Do not use `CF99.PLUS.02.04` to infer an eight-core 0.25 mm2 cable. Current public igus marketing tables and controlled data sheets have shown contradictory core-count text for that article. WB21 does not depend on it.

`CF99.PLUS.01.08` is the only CF99.PLUS candidate used here because its 8 x 0.14 construction and Ø8 mm envelope are consistent in the controlled data used for the calculation.

### Procurement hold

The cable is technically controlled and currently an active igus family, but a source compliant with the PX-1 ChipDip/marketplace procurement rule has not yet been frozen. Therefore this is a **technical baseline, not a released purchase item**.

Do not silently replace it with an unknown marketplace drag-chain cable merely because the printed cross-section is similar.

## 4. Eight-core allocation

The six functional circuits remain unchanged while power uses parallel conductors:

- two 0.14 mm2 cores in parallel -> `+12V_HEAD`;
- two 0.14 mm2 cores in parallel -> `GND_HEAD`;
- one core -> `HEAD_UART_TX`;
- one core -> `HEAD_UART_RX`;
- one core -> `CVBS_SIGNAL`;
- one core -> `CVBS_RETURN`;
- overall braid -> shield/functional EMC bond as qualified; **never DC power return**.

At the six-contact head connector, the two +12 V conductors terminate to the one +12 V contact and the two GND conductors to the one GND contact. Purchased SP13 hardware must prove that this doubled termination fits and survives wet vibration before release.

## 5. Electrical screen

Conservative transient head-current reservation:
- TILT N20 stall: 1.10 A;
- ROLL N20 stall: 1.10 A;
- RunCam reservation: 0.12 A;
- two LED channels: 0.60 A;
- total screen: **2.92 A**.

With two equal 0.14 mm2 conductors in parallel per power leg:
- current/core at the 2.92 A transient = about 1.46 A;
- effective resistance of one power leg = 70 ohm/km;
- for a conservative 0.40 m complete local harness, loop resistance = about 0.056 ohm;
- voltage drop at 2.92 A = about 0.164 V, or 1.36% of 12 V.

This is an electrical screen only. Final current distribution, contact heating and motor-start video noise require the physical harness.

## 6. Body ingress

Selected mechanical candidate:

**LAPP SKINTOP MS-M M16x1.5, article 53112010**

Controlled dimensions used:
- cable range: 4.5...10 mm;
- M16x1.5;
- wrench size 20 mm;
- outer body envelope approximately Ø22 mm;
- thread length 7 mm;
- manufacturer protection class IP68/IP69.

Because LAPP tables/data-sheet revisions show 31...33 mm total-length presentation, WB21 deliberately screens a conservative **26 mm external length** beyond the threaded mounting plane.

Current mounting screen datum:
- pressure-roof mount: `X180 / Y0 / Z60 mm`;
- fixed fairlead: `X190.5097 / Y-13 / Z95.7383 mm`;
- conservative gland end: `X186.9257 / Y-8.5668 / Z83.5509 mm`.

Ideal DN150 clearances:
- gland envelope: ~38.82 mm;
- Ø26 mounting-boss screen: ~56.00 mm;
- fixed cable section to fairlead: ~28.32 mm.

The M16 boss is a new pressure-boundary feature and is **not machining released** until pressure analysis/proof and leak testing are complete.

## 7. Controlled flex geometry

The moving clamp is placed on the inner side of the lower left lift arm:
- distance from lower body pivot: **60.0 mm**;
- Y datum: **-13.0 mm**.

The fixed fairlead is intentionally offset from the pivot axle so the Ø8 cable does not occupy the Ø8-class pivot hardware envelope.

Free flex centreline length:
- nominal: **52.8 mm**;
- assembly screen tolerance: **±0.5 mm**.

### LOW
- moving clamp: `X141.7784 / Y-13 / Z77.5 mm`;
- endpoint chord: 52.0324 mm;
- nominal circular free-flex radius: 89.19 mm;
- radius with +0.5 mm worst slack: 70.30 mm;
- cable-to-wet-deck screen: 22.81 mm;
- ideal DN150 cable clearance: 25.42 mm.

### MID
- moving clamp: `X141.4253 / Y-13 / Z105.0 mm`;
- endpoint chord: 49.9506 mm;
- nominal radius: **46.01 mm**;
- radius with +0.5 mm worst slack: **42.99 mm**.

MID is the bend-radius limiting position. It still exceeds the 40 mm / 5xd WB21 gate.

### HIGH
- moving clamp: `X167.6002 / Y-13 / Z142.5 mm`;
- endpoint chord: 52.0721 mm;
- nominal radius: 91.60 mm;
- radius with +0.5 mm worst slack: 71.43 mm.

HIGH is not a DN150 operating position. Its negative ideal DN150 pipe-clearance number is expected and is not a WB21 failure.

## 8. Executed collision screen

CadQuery 2.8.0 checks were run with:
- four lift arms at LOW/MID/HIGH;
- ten Z50 gear solids;
- WB20 gas-spring geometry;
- Ø22 gland envelope;
- Ø26 pressure-boss envelope;
- Ø12 fixed guide/support envelope;
- Ø8 dynamic cable;
- WB20 fixed camera/yoke package;
- moving camera package across TILT `-105...+105 deg` sampled every 1 degree.

Executed result:
- dynamic cable vs all four arms: 0 mm3;
- cable vs Z50: 0 mm3;
- cable vs gas spring: 0 mm3;
- gland/boss/support vs lift arms: 0 mm3;
- support vs gas spring: 0 mm3;
- cable vs fixed camera package: 0 mm3;
- cable vs moving camera throughout the 1-degree TILT sweep: 0 mm3.

Status: **PASS_SCREEN**.

## 9. Why this is better than WB19

WB19 proved that a free cable routed over the upper body could be made geometrically possible, but it required a large change in shortest path between lift positions and left only small dirty-pipe margins.

WB21 instead localizes motion to one small flex zone next to the lift pivot. The rest of the cable can be clamped to the arm and therefore moves as part of the linkage rather than storing/removing a large loop.

This is both closer to the source MiniCam service philosophy and easier to protect with a lift-arm cover.

## 10. Remaining HOLDs

1. obtain `CF99.PLUS.01.08` from an allowed procurement source or explicitly approve a special-cable sourcing exception;
2. measure purchased cable OD and real free-bend behaviour;
3. set 52.8 ±0.5 mm free length on a physical LOW/MID/HIGH jig;
4. perform wet/grit cycle test; project minimum is 500 lift cycles, with inspection for jacket polish/cracking/migration;
5. detail fairlead material, dirt drainage, fasteners and anti-chafe radius;
6. pressure-proof the M16 body boss and leak-test the assembled gland;
7. prove doubled +12/GND terminations fit the selected SP13 contacts;
8. qualify shield bond and CVBS with TILT/ROLL motor starts and LED PWM;
9. run physical dirty/oval DN150 sweep;
10. WB22 must close the **static** run from the moving clamp to the final camera connector without changing the WB21 pivot-flex datum unless a demonstrated collision requires it.

## 11. Next work block

**WB22 — moving-arm static harness / final SP13 interface.**

WB22 will design:
- cable support along the lower lift arm;
- lift-arm cover / anti-snag protection;
- transition from `Y=-13` flex clamp to the camera-side connector;
- final SP13/SP1324 decision based on actual purchasable six-contact hardware;
- service replacement sequence without opening the crawler pressure body.

## Change log

### 2026-09-11 — WB21
- discarded the WB19 upper-body slack-loop concept for manufacturing;
- recovered MiniCam's separate camera-connector + lift-housing-gland principle from source drawings;
- rejected unverified `CF10.02.06` and conflicting `CF99.PLUS.02.04` assumptions;
- selected `CF99.PLUS.01.08` as the controlled technical cable candidate;
- allocated two parallel conductors each to +12 V and GND;
- selected LAPP 53112010 M16 gland as body-ingress candidate;
- optimized fixed fairlead and 60 mm moving-clamp datum;
- established 52.8 ±0.5 mm constant free-flex length;
- executed LOW/MID/HIGH solid collisions and full 1-degree TILT cable sweep;
- retained manufacturing and procurement holds.

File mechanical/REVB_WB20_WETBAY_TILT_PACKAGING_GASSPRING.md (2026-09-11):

# PX-1 Rev.B — WB20 full-crawler correction: wet bay / TILT stack / electronics packaging / gas spring

Date: 2026-09-11  
Status: **PASS_SCREEN / MANUFACTURING HOLD**

## 1. Why WB20 exists

WB20 was opened after integrating the WB18/WB19 camera model with the complete Rev.PR crawler geometry.
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

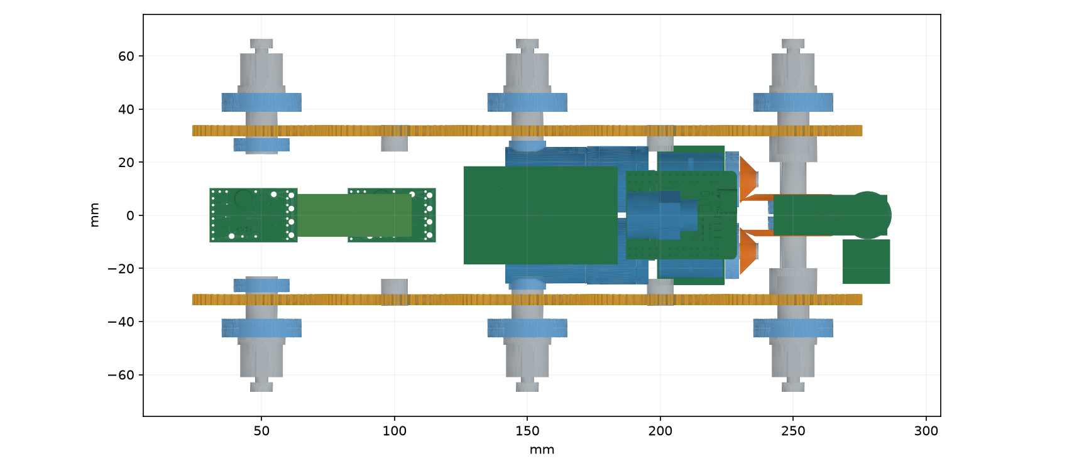
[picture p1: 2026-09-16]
current/images/PX1_Drive_Electronics.png

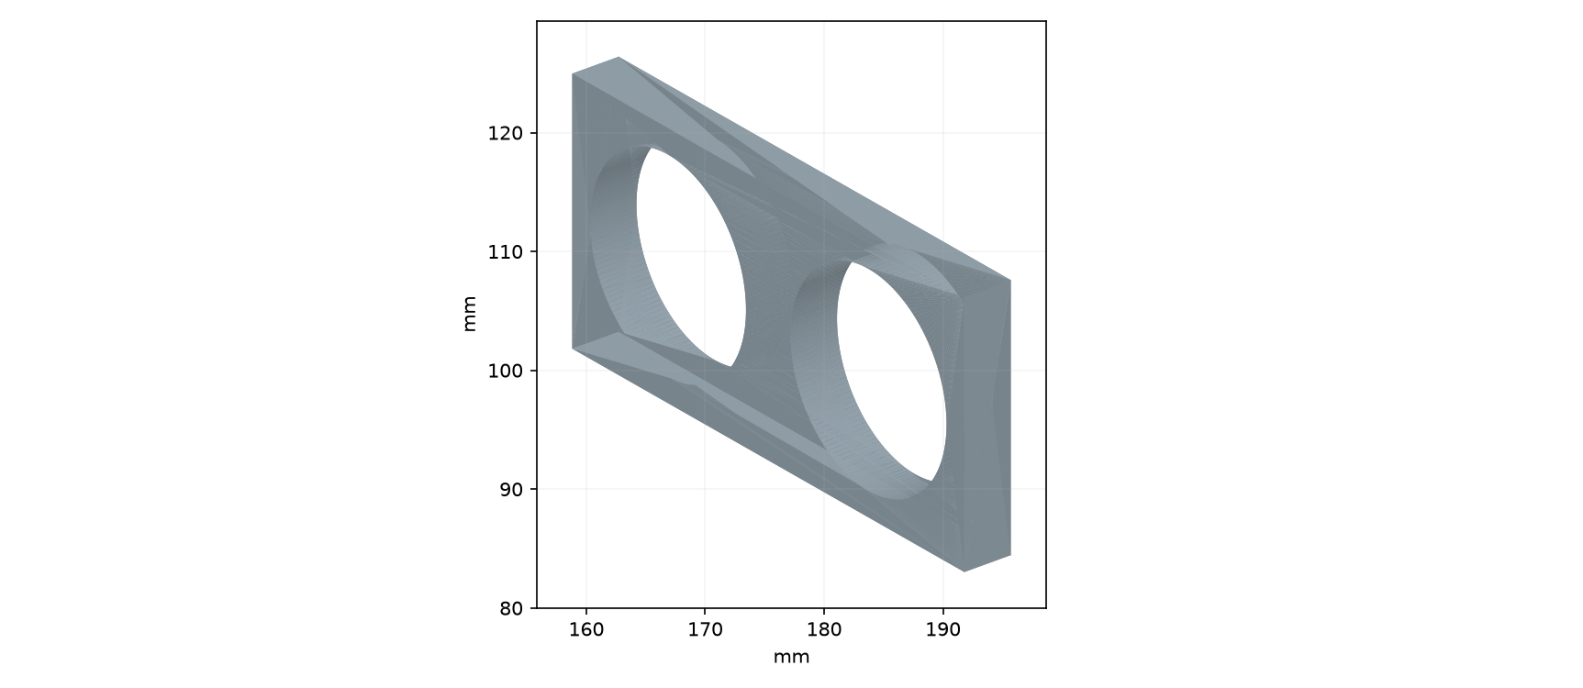
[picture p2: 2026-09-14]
current/images/part_026.png

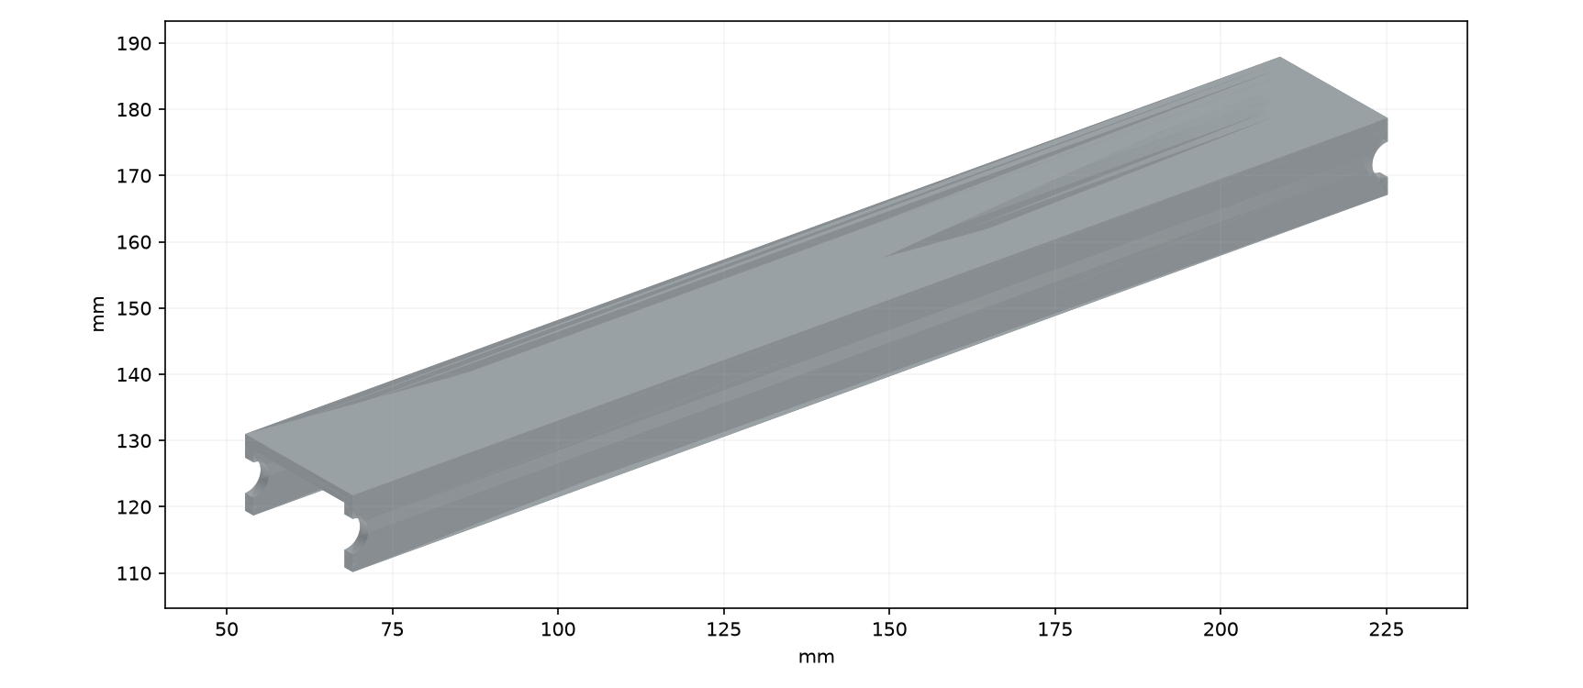
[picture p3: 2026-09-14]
current/images/part_032.png

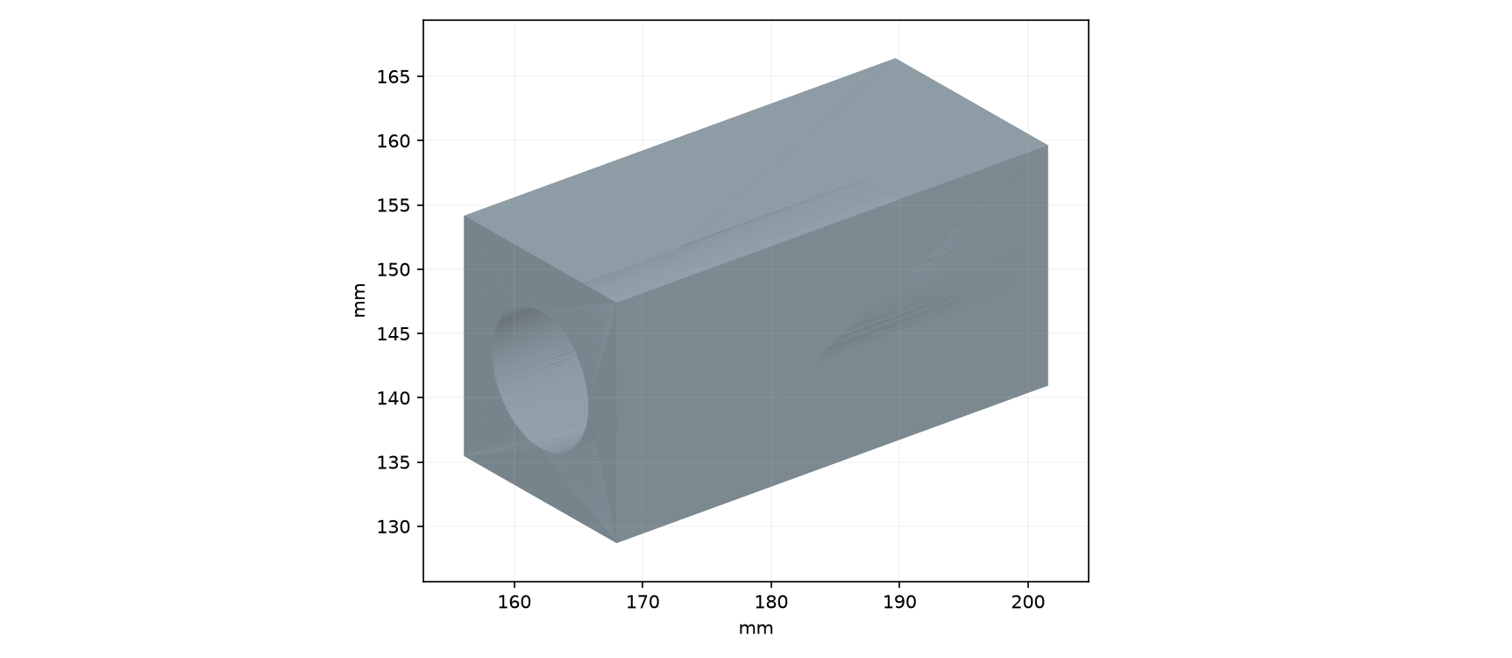
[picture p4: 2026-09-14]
current/images/part_028.png

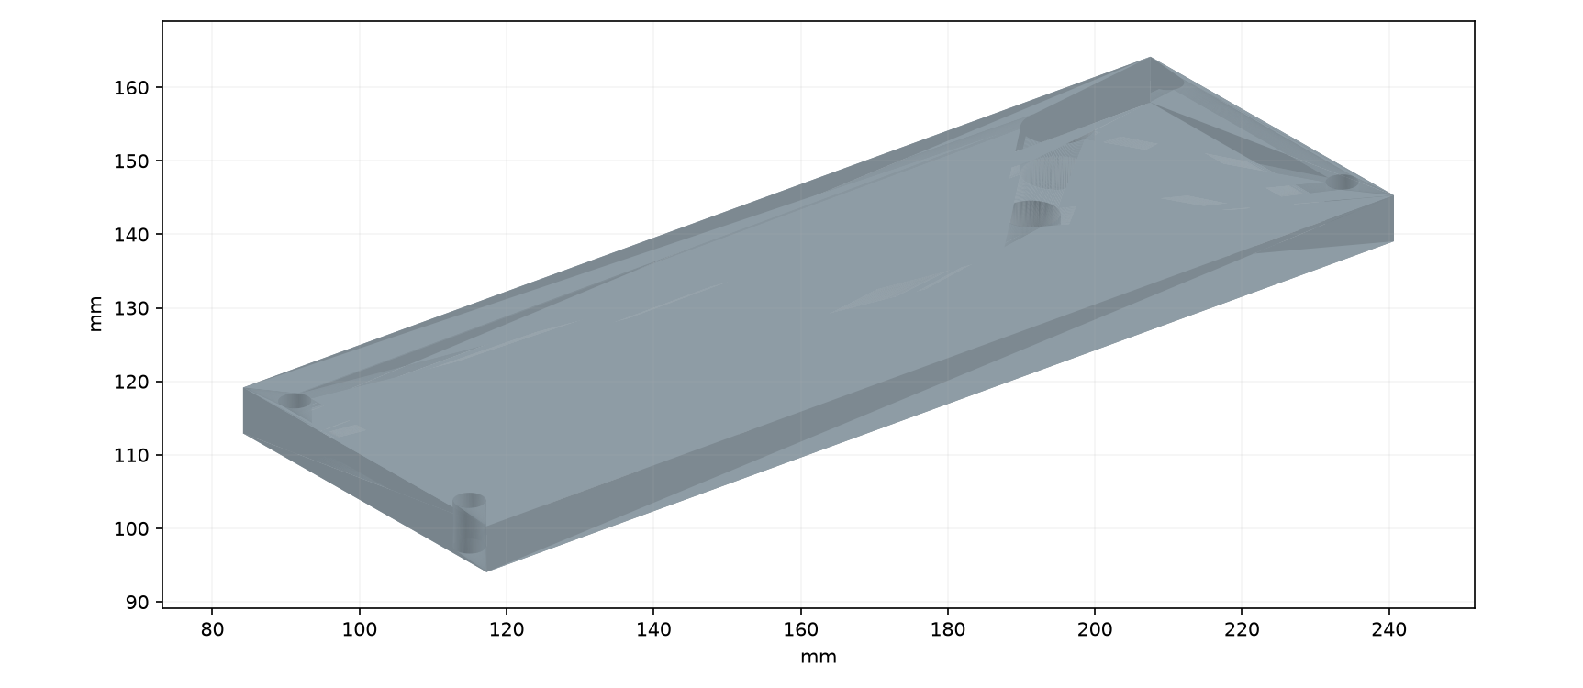
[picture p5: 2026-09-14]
current/images/part_027.png

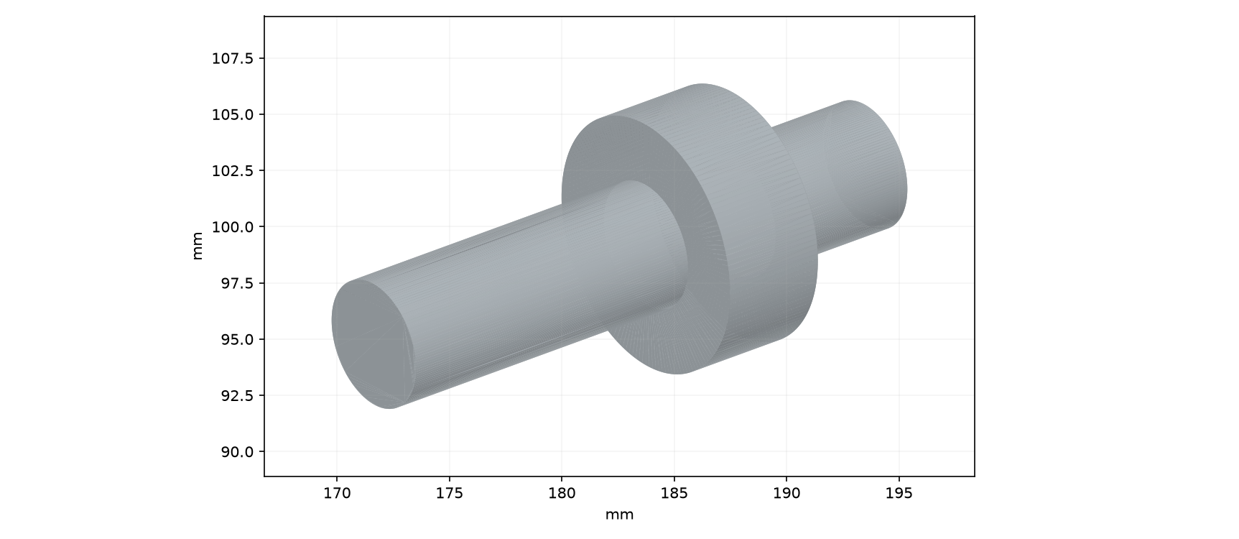
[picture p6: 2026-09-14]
current/images/part_021.png

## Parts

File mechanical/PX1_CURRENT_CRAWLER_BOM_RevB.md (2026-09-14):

# PX1 Current BOM - FINAL CURRENT (HOLD-aware)

| Item | Qty | Article/source | Dimension/spec | State |
|---|---:|---|---|---|
| Pressure body | 1 | PX1 machined, Proteus CRP150-derived reconstruction | reconstructed screen | HOLD: missing controlled part dimensions |
| Side cover | 2 | PX1 / FAL-002-062 functional family | source topology | HOLD contour/groove |
| Z50 spur gear | 10 | GEA-002-528/529 family | m1 Z50 B4, PD50 OD~52 | HOLD final tooth form/material |
| 61801-2RS | 14 | standard bearing | 12x21x5 | 12 side-drive + 2 Z16 supports |
| 61903-2RS | 6 | standard bearing | 17x30x7 | source size |
| 61800-2RS | 2 | standard bearing | 10x19x5 | source size |
| X-ring | 6 | metric X-ring | 18.72x2.62 | source size; material sample gate |
| Shaft seal | 2 | radial shaft seal | 18x30x7 | source size |
| Side-cover O-ring | 2 | metric O-ring | 190x1.5 | source size; groove HOLD |
| Axle-flange O-ring | 6 | metric O-ring | 32x1.5 | source size |
| Z16 bevel gear | 2 | GEA-002-531 family | m1 Z16 | HOLD supplier drawing |
| Z40 bevel gear | 2 | GEA-002-530 family | m1 Z40 | HOLD supplier drawing |
| Traction motor | 2 | ISL PGM-32P-24-100-60-02 | 24V, Ø32x92, 100:1, 60rpm no-load | selected candidate |
| Rigid coupling | 2 | NBK MLR-20C-6-6 | Ø20 x 24, 6/6 bore | published dimensions |
| Wheel | 6 | MiniCam QRW90SR/150 | 90 mm nominal | HOLD exact profile/hub |
| Camera pan housing | 1 | PX1 CAM026-derived architecture | base OD ~62.5 mm from user caliper photo; hollow rotor/internal ring gear/thrust-bearing concept | HOLD final wall/fits/internal gear dimensions |
| Gas spring | 1 | ACE GS-12-20-V4A | Ø12 body, Ø4 rod, stroke20, L72 extended, 150N target | published family dims; end fitting gate |
| Service gland | 1 | LAPP 53112000 | M12x1.5, Ø17.6, Cmax26.5, cable 3.5-7 | published |
| Camera connector pair | 1 | WEIPU SP13 6-pin family | local exactly 6 circuits | sample/detail gate |
| Rear connector pair | 1 | WEIPU SP17 7-pin family, 6 used + 1 spare | plug Ø24.6 L56.5, panel M17 | selected; sample gate |
| Controller | 1 | STM32 NUCLEO-F446RE | 82.5x70 board class | selected |
| Traction H bridge | 2 | BTS7960 / IBT-2 ready module | board dependent | HOLD actual board dimensions |
| HV->24V DC/DC | 1 | Cincon CQB150W-110S24 | 57.9x36.8x12.7 | selected candidate |
| Pressure sensor | 1 | Adafruit MPRLS Product 3965 | 17.8x16.7x7.5, 0-25PSI absolute | selected; ambient-baseline firmware |
| HV capacitor | 1 | Nichicon UCS2D221MHD1TN | 220uF 200V, Ø18x25 | selected |
| 24->12 converter | 1 | LM2596 ready module | board dependent | HOLD actual board |
| 12->5 converter | 1 | MP1584 ready module | board dependent | HOLD actual board |
| RS-485 module | 1 | MAX485 ready module | board dependent | HOLD actual board |
| Local camera cable | 1 | 6x0.25mm² flex cable class | EXACTLY 6 insulated cores | HOLD article + flex/EMC |
| Main tether | 1 | professional 6-core reinforced copper + aramid | 40m prototype | HOLD article/RFQ/sample |

Binary STEP/PDF/STL deliverables and the controlling CSV are distributed in the current release ZIP.

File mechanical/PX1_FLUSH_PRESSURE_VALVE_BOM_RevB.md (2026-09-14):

# PX-1 WB24A flush PRESSURE valve — prototype BOM

Date: 2026-09-14
Status: **PROTOTYPE BOM / MACHINING + LEAK QUALIFICATION HOLD**

This BOM is for the small low-profile pressure/fill valve inside the WB23E removable service cover.

## Source-derived items and PX-1 equivalents

| Qty | Function | MiniCam source evidence | PX-1 prototype candidate | State |
|---:|---|---|---|---|
| 1 | Protection/service cap | FSS-001-844 CAMERA VALVE COVER | PX1 machined low-profile cap, M8x1 candidate, OD <=12 mm, exposed height <=1.5 mm target | DRAWING HOLD |
| 1 | Guided push shaft | FSS-001-843 CAMERA VALVE SHAFT | 316L turned shaft, ~3 mm class; exact grooves/stroke from bench prototype | DRAWING HOLD |
| 1 | Check ball | BEA-001-845 4MM BALL BEARING | 4.0 mm AISI 316 precision ball, Grade 100 class candidate | SAMPLE |
| 2 | Small seals | SEA-001-846 3 x 1 O-RING | FKM/FPM 3 x 1 mm, 70–75 Shore A initial prototype | SAMPLE |
| 1 | Source outer/secondary seal reference | SEA-001-848 6 x 1.5 O-RING | FKM/FPM 6 x 1.5 mm if retained by final insert geometry | GEOMETRY HOLD |
| 1 | Valve spring | SPR-001-847 | stainless compression spring, wire 0.5 / OD 3.7 / free L 7.9 mm | SAMPLE |
| 1 | Lower spring/flow retainer | source assembly-specific | PX1 316L perforated retainer/plug | DRAWING HOLD |
| 1 | Seat | source detail not controlled | replaceable FKM soft seat around gas orifice, geometry from leak bench | TEST HOLD |
| 1 | Fill/purge adapter | official Proteus service method uses screw-on adaptor | PX1 M8x1 screw-on service adapter with mechanical opening probe and purge screw | TOOL PROTOTYPE |

## Commercial evidence for prototype parts

### Spring

MiniCam source BOM gives `SPR-001-847` geometry `d0.5 / De3.7 / L0 7.9 mm`.

That exact geometry exists as a standard spring rather than requiring a custom winding. Examples found during the current availability check:

- Febrotec `0X-DF1333` / `D11160` class, OD 3.7 mm, wire 0.5 mm, free length 7.9 mm;
- STAMO `VI4835`, DIN 2098/2098R, stainless steel, 0.5 x 3.7 x 7.9 mm.

Important: these examples prove that the geometry is standard. The project's allowed procurement-source rule still applies; locate the same DIN geometry on an approved marketplace/source before final BOM release if these suppliers are not approved for the build.

Do not freeze the spring rate merely from geometry. Current standard examples around this geometry are quite stiff, so the actual valve opening stroke/preload is set on the bench with the screw-on adaptor mechanically opening the valve.

### 3 x 1 FKM O-rings

Standard FKM/FPM/Viton 3 x 1 mm rings are widely catalogued at 70–80 Shore A. Start with 75 Shore A for dry/wet leak experiments and compare 70 Shore A only if seat friction/sealing requires it.

### 6 x 1.5 FKM O-ring

Standard FKM 6 x 1.5 mm exists as a normal metric size. It is retained only if the final PX1 insert geometry benefits from this source-like secondary/static seal; do not force the source size into a different PX1 gland.

### 4 mm ball

AISI 316 4 mm Grade-100 loose balls are commercially available. AISI 316 is preferred for the first wastewater-corrosion sample; hardened 440 stainless can be A/B tested if seat wear or dimensional finish is better, but 440 corrosion performance must be checked in the actual environment.

## Material / manufacturing candidates

### Shaft and retainer

- 316L stainless first choice;
- polish the O-ring-running area after turning;
- no sharp groove edges on dynamic seals;
- final surface finish and O-ring gland proportions come from the actual selected ring datasheet/ISO 3601 practice, not from guessed CAD.

### Protection cap

Two candidates:

1. 316L stainless — robust, compact, but protect aluminium threads from galling;
2. hard-anodized 6082 aluminium — low galvanic mismatch/weight, but inspect thread wear.

The cap is not allowed to become the primary pressure seal. Valve must pass pressure decay **with cap removed**.

### Seat

Prototype A uses a replaceable FKM soft seat so minor contamination does not rely on perfect metal-to-metal contact. If repeated-cycle testing shows the soft seat extrudes/wears, compare a precision conical metal seat with the same 4 mm ball.

## Quantity for first bench build

Make/buy enough for at least three complete insert sets:

- Set A1: guided-shaft / FKM seat;
- Set A2: duplicate guided-shaft build for repeatability;
- Set B1: simplified ball-check without guided shaft seals.

Recommended consumables for testing:

- >=20 x 3 x 1 FKM rings;
- >=10 x 6 x 1.5 FKM rings if retained;
- >=10 x 4 mm balls;
- >=10 x springs of the selected geometry.

This allows deliberate contamination, damage and repeated rebuilds without treating one successful assembly as proof.

## Release gates

Do not move these parts to production BOM until:

- real dimensions are recorded;
- opening stroke is repeatable;
- primary valve holds +0.25 bar for the qualified decay interval with protection cap removed;
- submerged bubble test passes;
- adaptor mate/unmate >=100 cycles passes;
- grit/dirty-water mouth contamination test passes;
- purge operation reduces crawler pressure to ambient reliably;
- WB24A final cap/adapter/seat drawing is released.

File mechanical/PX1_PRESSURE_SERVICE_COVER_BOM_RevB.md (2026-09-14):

# PX-1 WB23E/WB23G/H pressure/camera service assembly — prototype BOM

Date: 2026-09-14
Status: **BOM CANDIDATE / PROCUREMENT + QUALIFICATION HOLD**

This BOM is limited to the pressure-service cover and local camera/lift harness assembly.

| Qty | Item | Candidate article / material | Requirement | Installation | State |
|---:|---|---|---|---|---|
| 1 | Pressure/camera service cover | EN AW-6082-T6 machined plate | **86 x 44 x 6 mm** | top pressure roof, two M4 screws | WB23E screen PASS |
| 2 | Cover screws | A4 stainless M4, retained preferred | centres X226 / X296; length TBD from final boss engagement | blind threaded bosses | sample HOLD |
| 1 | Cover seal | 2.0 mm FKM cord or molded equivalent | provisional groove width 2.5 mm; final groove from real elastomer | continuous closed perimeter | groove HOLD |
| 1 | Cable gland | LAPP SKINTOP MS-M `53112000` | M12x1.5, 3.5–7 mm cable | horizontal forward-facing boss | candidate controlled |
| 1 | Pressure/fill valve | very low-profile service valve | preferred exposed envelope <=Ø12 x 5 mm; prototype hard screen <=Ø14 x 6 mm | service cover around X273/Y0 | article HOLD |
| 1 | Valve protection cap | compact/recessed preferred | cap included in pressure-port hard envelope | fill valve | HOLD |
| 1 | Dry receptacle housing | Molex Micro-Fit 3.0 `43025-0600` | 6 circuits | internal dry harness side | WB23G candidate |
| 1 | Dry plug housing | Molex Micro-Fit 3.0 `43020-0601` | 6 circuits, no panel ears | internal dry mating side | WB23G candidate |
| 6 | Female crimp contacts | Molex `43030-0007` | tin; 20/22/24 AWG; insulation <=1.85 mm | `43025-0600` | exact sample article |
| 6 | Male crimp contacts | Molex `43031-0007` | tin; 20/22/24 AWG; insulation <=1.85 mm | `43020-0601` | exact sample article |
| 1 | **Primary flex cable sample** | LAPP UNITRONIC FD P plus A `0028679` | exactly 6 x 0.25 mm²; nominal OD 5.4 mm; PUR; continuous-flex; unshielded | gland -> lift -> SP13 | PRIMARY SAMPLE / EMC HOLD |
| 1 | Shielded A/B cable sample | LAPP UNITRONIC LiYCY `0034406` | 6 x 0.25 mm²; shielded; nominal OD ~6.0 mm | same prototype route | FLEX-LIFE HOLD |
| 1 | Optional shielded high-cycle reference | Pepperl+Fuchs six-core PUR cordset cable construction | 6 x 0.25 mm²; OD 6.0 mm; foil+braid; >=2M chain cycles; moving R >10D | comparison only | sourcing/bend HOLD |
| 1 | Camera cable plug | WEIPU `SP1310/S6I-N` | 6 sockets; cable range 4.0–6.5 mm | lift-harness end | WB15 candidate |
| 1 | Camera panel connector | WEIPU `SP1312/P6-C` | 6 male contacts | sealed camera rear panel | WB15 candidate |
| 1 | Lift-arm harness guard | 1 mm stainless/Al or printed fit prototype | conservative outside envelope ~10 mm; drain-open/removable | protects lower-arm straight run | WB23G screen PASS |
| 1 | Internal strain-relief clamp | P-clamp / machined clamp | fits real cable without jacket damage | before dry Micro-Fit connector | HOLD |

## Six-core allocation

1. +12V_HEAD
2. GND_HEAD
3. UART_TX
4. UART_RX
5. CVBS_SIGNAL
6. CVBS_RETURN

A cable screen, if present, is EMC only and is never a DC return conductor. The six insulated circuits do not change between screened and unscreened samples.

## Cable decision rule

Do not choose the production cable by the word `shielded` alone. The wet lift harness must survive repeated movement and must also carry stable raw CVBS/UART.

Current priority:

1. test LAPP `0028679` because its exact six-core/0.25-mm²/5.4-mm PUR continuous-flex construction best fits the mechanical duty;
2. test a shielded 6 x 0.25 sample in the same electrical setup;
3. if unshielded 0028679 passes the complete motor/LED/video interference test, do not make the harness thicker merely to add a screen;
4. if it fails EMC, reopen screened high-flex cable/backshell choice using measured evidence.

Do not substitute a 7-core cable. SAB SD90C and similar families may be excellent but a standard 7 x 0.25 article does not meet the frozen six-core architecture.

## WB23E cover/opening control values

- cover centre X261 / Y0;
- cover 86 x 44 x 6 mm;
- service opening 48 x 22 mm;
- opening X237...285 / Y-11...+11;
- two M4 centres X226 / X296;
- provisional groove centre path offset 4.0 mm from opening edge;
- provisional groove width 2.5 mm;
- minimum M4 clearance-hole edge to provisional groove outer edge 3.5 mm;
- minimum M4 head edge to cover outer edge 4.0 mm;
- minimum provisional groove outer edge to cover Y edge 5.75 mm.

The groove depth/compression is not machining release until the real seal is selected.

## WB23G packaging correction

WB23G validates a six-core cable hard envelope up to Ø6.5 mm with a 10 mm conservative arm-guard envelope. LOW guard ideal-DN150 clearance remains about 27.78 mm with no collision against Z50 or the camera envelope.

## Material notes

- Cover: 6082-T6 first-machined prototype target; final surface treatment after corrosion/fit trials.
- Seal: FKM preferred initial wastewater/chemical candidate; NBR acceptable only for early dry bench work unless subsequently qualified.
- Fasteners: A4 stainless preferred externally; final torque depends on thread engagement, lubrication and gasket compression.

## Do not bulk-order yet

Do not bulk-order custom covers, cable, molded seals, fill valves or SP13/Micro-Fit quantities until first pressure/flex/electrical qualification passes. Buy only enough for prototype samples and destructive/backup tests.

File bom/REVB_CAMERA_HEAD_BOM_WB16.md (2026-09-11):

# PX-1 Rev.B — camera-head controlled BOM / WB16

Date: 2026-09-11
Status: PROTOTYPE PROCUREMENT LIST / SUPERSEDES WB15 BOM WHERE HARNESS OR CABLE-PLUG VARIANT DIFFERS

| Item | Qty | Exact article / family | Current source status | Controlled data | Installation | Release status |
|---|---:|---|---|---|---|---|
| Analog camera | 1 + 1 spare preferred | RunCam Phoenix 2 `PHOENIX2-SL` family | manufacturer/marketplace routes | ~19 x 19 x 19...20 mm; 5...36 V; CVBS | removable carrier inside integrated ROLL frame | SELECTED / SAMPLE HOLD |
| Internal ROLL slip ring | 1 + 1 spare | SenRing `M125-06` | manufacturer standard family | Ø12.5 x 13.5 mm; 6 x 1.5 A | non-structural coaxial transfer inside 6803 ID17 passage | SELECTED / VIDEO HOLD |
| ROLL bearings | 2 | 6803-2RS / 61803-2RS | exact brand HOLD | 17 x 26 x 5 mm | spaced seats in integrated ROLL spindle/carrier | GEOMETRY RETAINED |
| Head panel connector | 1 + 1 spare | WEIPU `SP1312/P6-C` | current active/orderable | 6 male; 5 A/contact; 125 V; IP68 family; OD ~19.5; M13x1; panel cutout Ø13 / 11.8 flat; panel <=3.5 | non-TILT rear support/yoke-base bulkhead, 3.0 mm land | SELECTED / PRESSURE+VIDEO HOLD |
| Lift-harness cable connector | 1 + 1 spare | WEIPU `SP1310/S6II-N` | active; current distributor/marketplace listings | 6 female; 5 A/contact; 125 V; cable OD 5...8 mm; ~Ø18.8 x 49 mm | cable side; powered harness uses recessed sockets | SELECTED / SAMPLE HOLD |
| External manual-lift harness cable | buy 3 m; final cut <=0.50 m each until routing freeze | LAPP `0027429` UNITRONIC FD CY 7X0.25 | current product; TME Czech displayed 200 m at latest check | 7 x 0.25 mm²; OD6.7; shielded; 79 ohm/km max/core; continuous-flex; dynamic Rmin50.3 | along one parallelogram arm, design R>=55; six used cores + one insulated spare | SELECTED / DN150 ROUTE+CVBS HOLD |
| Video balun | 2 system ends | Delta-Opti `TR-1D*P2`, EAN 5902887011313 | current route verified | body ~16 x 15 x 43 mm + local BNC lead | crawler fixed side after lift harness; CCU second end | SELECTED / COMPLETE LINK HOLD |
| White LEDs | 6 + 2 spares | Cree XP-G / XP-G3 family; prior target `XPGDWT-B1-0000-00LE2` where traceable | exact bin HOLD | 3535 class | six 8 mm MCPCB sites PCD40 | FAMILY SELECTED |
| Small LED MCPCB | 6 + spares | standard 8 mm 3535 aluminium MCPCB | marketplace | Ø8 class | shallow pocket + thermal compound + clamp | PROTOTYPE SOURCE |
| LED driver | 2 + 1 spare | `P4115adj` ready module | active marketplace route | ~29.3 x 15.1 x 9 mm | fixed-side head electronics; 1 per 3-LED string | SELECTED / THERMAL HOLD |
| Optical window | 1 + spare | tempered mineral glass or sapphire candidate | exact article HOLD | target Ø28 x 3 | static FKM-sealed mechanical retention | GEOMETRY TARGET |
| Camera lens | 1 | stock RunCam M12 2.1 mm initially | included | wide FOV | M12, locked after focus | DEMO BASELINE |
| Local controller | 1 | RP2040-Zero-class ready module | marketplace | ~18 x 23.5 mm class | fixed side relative to continuous ROLL | PACKAGING HOLD |
| Camera-axis motor | 2 | `DCGM-N20-12V-EN-200RPM` family | selected project article/source gate | 12 V; ~200 rpm; encoder; 1:150; stall <=1.1 A target | TILT and ROLL drive stations | SELECTED / SAMPLE HOLD |
| Camera-axis drivers | 2 | DRV8871-class ready modules | exact board source HOLD | module envelope sample-driven | one per axis | FAMILY RETAINED |
| Internal TILT electrical transfer | TBD | WB17 | not frozen | must accommodate ±105 deg without violating head pressure boundary | source-like integrated wiring/feedthrough, no cartridge | WB17 BLOCKER |

## WB16 external harness colour map

- WH = +12V_HEAD
- BN = GND_HEAD
- GN = HEAD_UART_TX
- YE = HEAD_UART_RX
- GY = CVBS_SIGNAL
- PK = CVBS_RETURN
- BU = NC_SPARE_HEAD

Numeric SP13 contact numbers remain HOLD until actual sample continuity mapping.

## Procurement action for first bench build

Buy first:
- 3 m LAPP 0027429;
- 2 x WEIPU SP1310/S6II-N;
- 2 x WEIPU SP1312/P6-C;
- one additional spare of each connector half if cost allows.

Do not buy `SP1310/S6I-N` for the LAPP 0027429 harness: its 6.5 mm maximum cable range is below the selected cable nominal 6.7 mm.

## Supersession note

WB15 BOM references to `SP1310/S6I-N` are superseded by this file because WB16 selected the real cable article after WB15 connector screening.

The panel connector, six electrical functions, pressure test requirement and mechanical register remain unchanged.

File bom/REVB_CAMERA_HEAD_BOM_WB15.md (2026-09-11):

# PX-1 Rev.B — camera-head controlled BOM / WB15

Date: 2026-09-11
Status: PROTOTYPE PROCUREMENT LIST / SUPERSEDES WB14 BOM FOR ACTIVE HEAD INTERFACE

| Item | Qty | Article / family | Source status | Controlled dimensions / ratings | Installation | Release status |
|---|---:|---|---|---|---|---|
| Analog camera | 1 + 1 spare preferred | RunCam Phoenix 2, `PHOENIX2-SL` family | manufacturer active; marketplace routes exist | ~19 x 19 x 19...20 mm; 5...36 V; M12 lens | removable carrier inside integrated ROLL frame | SELECTED / SAMPLE HOLD |
| Internal ROLL slip ring | 1 + 1 spare | SenRing `M125-06` | manufacturer standard-stock family | Ø12.5 x 13.5 mm; 6 x 1.5 A; AWG30 leads | coaxial non-structural transfer inside 6803 ID17 passage | SELECTED / VIDEO TEST HOLD |
| ROLL bearings | 2 | 6803-2RS / 61803-2RS | exact brand/source HOLD | 17 x 26 x 5 mm | spaced seats in integrated inner ROLL spindle/carrier | GEOMETRY RETAINED / BRAND HOLD |
| Head panel connector | 1 + 1 spare | WEIPU `SP1312/P6-C` | exact active distributor stock verified | 6 pin; 5 A/contact; 125 V; IP68 family; OD ~19.5 mm; M13x1; panel cutout Ø13 with 11.8 flat; panel <=3.5 mm | centered in 3.0 mm rear bulkhead within Ø36 mechanical register; rear-nut mount | SELECTED / PRESSURE+VIDEO HOLD |
| Crawler/lift cable connector | 1 + 1 spare | WEIPU `SP1310/S6I-N` | exact active distributor stock verified | 6 socket; 5 A/contact; 125 V; IP68 family; OD ~18.8 mm; L ~49 mm; cable OD 4...6.5 mm | straight cable plug; female powered side; >=60 mm extraction clearance | SELECTED / HARNESS HOLD |
| Video balun | one camera-side + one CCU-side pair | Delta-Opti `TR-1D*P2`, EAN 5902887011313 | current marketplace route verified | body ~16 x 15 x 43 mm plus local BNC lead | crawler/lift fixed side after SP13; not inside continuous ROLL | SELECTED / COMPLETE-LINK TEST HOLD |
| White LED emitter | 6 + 2 spares | Cree XP-G / XP-G3 white family; prior target `XPGDWT-B1-0000-00LE2` where traceable | exact controlled-bin source HOLD | 3535 emitter class | six separate 8 mm MCPCB sites on PCD40 | FAMILY SELECTED / EXACT BIN HOLD |
| Small LED MCPCB | 6 + spares | standard 8 mm 3535 aluminium MCPCB | marketplace families indexed | 8 mm class; thickness sample-driven | shallow pocket + thermal compound + removable clamp ring | PROTOTYPE SOURCE / SAMPLE HOLD |
| LED current driver | 2 + 1 spare | `P4115adj` ready module | active marketplace route | ~29.3 x 15.1 x 9 mm; adjustable constant current | fixed-side head electronics; one per 3-LED string | SELECTED / DROPOUT+THERMAL HOLD |
| Front optical window | 1 + spare | tempered mineral glass or sapphire candidate | exact article/source HOLD | target Ø28 x 3 mm | static mechanically retained FKM-sealed window | GEOMETRY TARGET / SOURCE+GLAND HOLD |
| Camera lens | 1 | stock RunCam M12 2.1 mm for first test | included | ~155 deg class FOV | threaded M12; final focus/FOV test-driven | DEMO BASELINE / FINAL FOV HOLD |
| Narrower lens test | 1 if required | 5 mm M12, 1/2 in-compatible class | exact marketplace article HOLD | target ~75 deg horizontal class | substitute only after BFL/image-circle test | OPTICAL TARGET / PROCUREMENT HOLD |
| Fixed-side local controller | 1 optional | RP2040-Zero-class ready module | marketplace routes available | ~18 x 23.5 mm class | fixed head side only; never on continuous ROLL carrier | ARCHITECTURE OPTION / PACKAGING HOLD |
| Camera-axis drivers | 2 | DRV8871-class ready modules | exact board/source HOLD | board envelope sample-driven | fixed-side carrier, one per TILT/ROLL motor | FAMILY RETAINED / EXACT MODULE HOLD |
| Local six-core head harness | 1 | exact flexible 6-core cable TBD in WB16 | not frozen | must fit SP1310 version-I cable OD 4.0...6.5 mm | crawler/lift fixed harness to head connector | WB16 HOLD |

## External head logical allocation

The active six functions are:
- +12V_HEAD
- GND_HEAD
- HEAD_UART_TX
- HEAD_UART_RX
- CVBS_SIGNAL
- CVBS_RETURN

Numeric contact numbers remain HOLD until the first SP13 pair is physically inspected and front/rear-view numbering is confirmed.

## Procurement rule

A `HOLD` line is not permission to buy an arbitrary visual substitute.

Before machining around a purchased module, record:
- exact supplier/listing;
- manufacturer article;
- photo/label;
- measured X/Y/Z dimensions;
- mounting/lead exit;
- electrical revision where applicable.

## Errors closed through WB15

- larger CCTV board is not adopted because RunCam already satisfies analog/size requirement;
- Ø16 LED stars are rejected for Ø52/Ø28 front geometry;
- Ø22 M220 is rejected for camera internal ROLL because it cannot pass 6803 ID17;
- fixed-shell lighting and camera-axis drive currents do not cross internal ROLL;
- LEMO 0K.304 placeholder is retired because it has only four LV contacts;
- connector ingress rating is not treated as camera-head pressure proof;
- no cartridge/cassette camera mechanics are permitted.

## Next controlled BOM gate — WB16

Freeze:
- exact six-core local cable article/source;
- cable OD/bend radius;
- conductor cross-section;
- SP13 numeric contact map;
- local video/UART pairing and strain-relief geometry.

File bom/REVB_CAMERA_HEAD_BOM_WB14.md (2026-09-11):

# PX-1 Rev.B — camera-head controlled BOM / WB14

Date: 2026-09-11
Status: PROTOTYPE PROCUREMENT LIST / RELEASE HOLDS SHOWN EXPLICITLY

| Item | Qty | Article / family | Source status | Controlled dimensions | Installation | Release status |
|---|---:|---|---|---|---|---|
| Analog camera | 1 + 1 spare preferred | RunCam Phoenix 2, `PHOENIX2-SL` family | RunCam manufacturer active; AliExpress marketplace listings for standard Phoenix 2 currently indexed | ~19 x 19 x 19...20 mm; M12 lens; ~9 g | M2-based removable carrier inside integrated ROLL frame; real sample controls holes | SELECTED / SAMPLE HOLD |
| Camera slip ring | 1 | SenRing `M125-06` | Manufacturer standard-stock family; exact approved marketplace route still HOLD | Ø12.5 x 13.5 mm; 6 x 1.5 A; AWG30 leads | Coaxial non-structural rotary interface inside 17 mm ID ROLL bearing passage; retained by normal holder, not used as bearing | ENGINEERING SELECTED / PROCUREMENT+VIDEO HOLD |
| ROLL bearings | 2 | 6803-2RS / 61803-2RS family | exact brand/source HOLD | 17 x 26 x 5 mm | spaced bearing seats in ordinary integrated ROLL carrier | GEOMETRY RETAINED / BRAND HOLD |
| Video balun | 1 crawler-side half + matching CCU half | Delta-Opti `TR-1D*P2` pair, EAN 5902887011313 | current marketplace route verified | body ~16 x 15 x 43 mm plus local BNC lead | fixed side after camera slip ring; mechanically clipped/strain relieved | SELECTED / COMPLETE-LINK TEST HOLD |
| White LED emitter | 6 + 2 spares | Cree XP-G / XP-G3 white family; previous exact target `XPGDWT-B1-0000-00LE2` retained when traceable | exact controlled-bin source still HOLD; marketplace 8 mm XP-G3 assemblies exist for prototype | emitter 3535 class on 8 mm-class MCPCB | six separate thermally clamped positions on PCD40 | FAMILY SELECTED / EXACT BIN HOLD |
| Small LED MCPCB | 6 + spares | standard 8 mm 3535 aluminium MCPCB compatible with XP-G family | AliExpress marketplace families currently indexed in 8/10/12/14/16/20 mm sizes | 8 mm-class; actual thickness sample-driven | shallow front-carrier pocket + thermal compound + removable clamp ring | PROTOTYPE SOURCE / SAMPLE HOLD |
| LED current driver | 2 + 1 spare | `P4115adj` ready module | current Allegro marketplace listing | PCB 29.3 x 15.1 x 9 mm | fixed-side electronics carrier; one module per 3-LED string; screw/terminal service access | SELECTED / DROPOUT+THERMAL HOLD |
| Front optical window | 1 + spare | tempered mineral glass or sapphire candidate | exact article/source HOLD | current target Ø28 x 3 mm | static mechanically retained window with dedicated FKM seal; not adhesive-only | GEOMETRY TARGET / SOURCE+GLAND HOLD |
| Camera lens | 1 | stock RunCam 2.1 mm M12 for first test | included with camera | ~155 deg class FOV | threaded M12, focus locked only after pipe test | DEMO BASELINE / FINAL FOV HOLD |
| Narrower lens reference | 1 test article if required | 5 mm M12, 1/2 in sensor-compatible class | controlled manufacturer examples exist; approved marketplace exact article still HOLD | engineering target ~75 deg horizontal, lens OD ~17 mm class | replace stock M12 only after BFL/image-circle/focus check | OPTICAL TARGET / PROCUREMENT HOLD |
| Fixed-side local controller | 1 optional | RP2040-Zero class ready module | marketplace/official routes available; exact article not yet repurchased for WB14 | ~18 x 23.5 mm class | fixed side only; never on continuous ROLL carrier | ARCHITECTURE OPTION / PACKAGING HOLD |
| Camera-axis drivers | 2 | DRV8871-class ready modules | exact board/source HOLD | reference ~26 x 20 x 8 mm class | fixed-side carrier, one per TILT/ROLL motor | FAMILY RETAINED / EXACT MODULE HOLD |

## Procurement rule

A line marked `HOLD` is not permission to buy an arbitrary substitute of similar appearance.

Before machining around a purchased module, record:
- actual supplier/listing;
- photo/label;
- measured X/Y/Z dimensions;
- mounting-hole positions;
- connector/lead exit;
- electrical revision where applicable.

## Camera-specific errors now closed

- larger 34 mm CCTV board camera is not adopted because RunCam already meets the analog/packaging requirement;
- Ø16 star LED boards are not used in the Ø52/Ø28 front geometry;
- Ø22 M220 is not used in the camera because it conflicts with the 17 mm central ROLL passage;
- fixed-shell lighting does not cross the camera ROLL slip ring;
- no cartridge/cassette camera module is permitted;
- old digital/Ethernet Rev.FA camera path is historical and does not control this BOM.

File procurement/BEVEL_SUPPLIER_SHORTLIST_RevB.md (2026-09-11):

# PX-1 Rev.B — compact bevel supplier shortlist

Date: 2026-09-11
Status: SOURCING SHORTLIST — capability screening only, no supplier approved yet

Target RFQ: `RFQ_PX1_HARDENED_BEVEL_Z16_Z40_RevB.md`

## A. Czech custom-manufacturing candidates

### ZPA PRAGA, a.s.
Website: https://www.zpa-praga.cz/

Publicly stated capability:
- design and manufacture of bevel gears;
- straight teeth;
- curved Gleason and Oerlikon teeth;
- complete gear sets;
- small, medium and large series.

Why shortlisted:
- directly relevant bevel-gear specialization;
- manufacturer states both design and production capability;
- no public minimum module found on the reviewed page, so m1 feasibility must be asked explicitly.

RFQ priority: HIGH.

### Metalpreciz
Website: https://www.metalpreciz.cz/ozubena-kola/kuzelova-ozubena-kola

Publicly stated capability:
- custom bevel gears from customer drawings;
- straight and spiral bevel gears;
- piece and serial production.

Why shortlisted:
- explicitly advertises made-to-drawing bevel gears;
- suitable for a three-pair prototype inquiry.

RFQ priority: HIGH.

### ELITEX OK s.r.o.
Website: https://www.ozubenakola.eu/sortiment/

Publicly stated capability:
- custom gears and pinions;
- gears on cylindrical, conical and spherical surfaces;
- heat and thermo-chemical processing including hardening, carburizing, nitriding and high-frequency hardening;
- gear grinding on selected geometry.

Why shortlisted:
- unusually good match to the PX-1 need for custom geometry plus controlled hardening.

RFQ priority: HIGH.

### Strojírny Kalinowski
Website: https://strojirny.kalinowski.cz/cz/nase-produkce/vyroba-ozubeni.html

Publicly stated capability:
- manufacture of gearing;
- custom atypical bevel gearing by agreement;
- broad CNC/conventional gear-manufacturing capability.

Limit:
- public page does not clearly confirm m1 straight bevel capability or the required heat-treatment route.

RFQ priority: MEDIUM.

### TOS ZNOJMO
Website: https://d2.tos-znojmo.cz/cze/produkce/strojirenska-vyroba/kuzelove-soukoli/

Publicly stated capability:
- design, calculation, manufacture and measurement of straight and curved bevel sets;
- Gleason/Oerlikon capability.

Important limitation:
- published straight/curved bevel range starts at module 2 mm.

Decision:
- NOT a first-choice supplier for the exact m1 PX-1 pair;
- useful only if they can offer a special process outside the published range or advise a partner.

## B. Stock prototype / reference suppliers

### TYMA CZ
Product: `OKS M1 Z16/40 B (1:2.5, Steel)`
Website: https://www.tyma.cz/produkty/ozubena-kola-a-hrebeny/kuzelova-kola/modul-1/

Use:
- low-cost geometry/alignment/backlash mule only.

Not released for traction because:
- C45 teeth are explicitly not hardened;
- no verified allowable torque published on the reviewed product page.

### Mädler / AMECO stock straight m1 pair
Parts:
- 36056400 Z16;
- 36056500 Z40.

Use:
- dimensional reference only.

Rejected for traction because published allowable torque is only 0.09 N.m at Z16.

### Mädler / AMECO hardened spiral references
Examples:
- 38557200, m1, 20/50, 42CrMo4, induction-hardened, 2.5:1;
- 38566600, m1.3, 14/35, 42CrMo4, induction-hardened, 2.5:1.

Use:
- strength/material/process references only.

Rejected geometrically because large gear OD is about 75.7 / 70.9 mm respectively, much larger than the PX-1 ~41 mm class envelope.

## C. RFQ order

Send the same controlled RFQ package first to:
1. ZPA PRAGA;
2. Metalpreciz;
3. ELITEX OK.

Then compare:
- confirmed m1 capability;
- tooth system;
- material;
- heat treatment;
- quoted continuous/transient pinion torque;
- mounting-distance/backlash control;
- matched-pair inspection;
- prototype quantity price;
- lead time.

Do not choose the cheapest quotation until the supplier explicitly confirms the torque and heat-treatment requirements.

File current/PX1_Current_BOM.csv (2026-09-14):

item | name_ru | qty | article | dimensions | source | route | cad_state | release
M01 | Корпус | 1 | CRP150 корпус DRW375 | ≈278×68×64 | DRW375 | MILL | GRAPHIC_APPROX | H02 H03
M02 | Боковая крышка | 2 | FAL-002-062 | ≈262×60×7 | DRW374 | MILL | GRAPHIC_APPROX | H02 H03
M03 | Фланец оси | 6 | FSS-002-061 | OD≈50 | DRW374 | TURN | GRAPHIC_APPROX | H02 H03
M04 | Короткая ось | 4 | FSS-002-063 | ступени12/17/18 длиныHOLD | DRW374 | TURN | GRAPHIC_APPROX | H02
M05 | Длинная ось | 2 | FSS-002-064 | задняяX250 соединениеHOLD | DRW374 | TURN | GRAPHIC_APPROX | H02 H04
M06 | ВалZ40 | 2 | FSS-002-066 family | 10/18 socket12 provisional | DRW375 | TURN | ADAPTATION | H02 H04
M07 | ВалZ16 | 2 | FSS-002-083 family | 6/12 длиныHOLD | DRW386 | TURN | ADAPTATION | H04 H05
M08 | Парный держатель моторов | 1 | PX1-25D-HOLDER | 52.8×30×3 отверстия2×2M3/17 | Pololu dimension diagram | MILL | ADAPTATION | H05
M09 | Держатель опорZ16 | 1 | PX1-PINION-HOLDER | 52.8×26×5 | DRW386 topology | MILL | ADAPTATION | H04 H05
M10 | Разрезная переходная втулка | 2 | PX1-SPLIT-6-4 | OD6 ID4 L8 | NBK/Pololu interfaces | TURN | ADAPTATION | H05
M11 | Палец холостойZ50 | 4 | PX1 idler pin | 10 длинаHOLD | DRW374 | TURN | GRAPHIC_APPROX | H02
G01 | Z50 на осях | 6 | GEA-002-529 | Z50 B4 m1 inferred | DRW374 | GEAR | ANALYTIC_20DEG_HOLD | H04
G02 | Z50 холостая | 4 | GEA-002-528 | Z50 B4 m1 inferred | DRW374 | GEAR | ANALYTIC_20DEG_HOLD | H04
G03 | Z40 | 2 | GEA-002-530 | Z40 m1 inferred | DRW375 | GEAR | CONICAL_ENVELOPE | H04
G04 | Z16 | 2 | GEA-002-531 | Z16 m1 inferred | DRW386 | GEAR | CONICAL_ENVELOPE | H04
B01 | Подшипник61801 | 4 | BEA-002-701 /61801-2RS | 12×21×5 | DRW374+386 | BUY | BOUNDARY | ПосадкиH02
B02 | Подшипник61903 | 6 | BEA-002-704 /61903-2RS | 17×30×7 | DRW374 | BUY | BOUNDARY | ПосадкиH02
B03 | Подшипник61800 | 2 | 61800-2RS | 10×19×5 | DRW375 | BUY | BOUNDARY | ПосадкиH02
B04 | Втулка холостой шестерни | 4 | BEA-002-537 | 10-12-4 | DRW374 | BUY | BOUNDARY | H02
B05 | Втулка средней оси | 2 | source12-14-4 | 12-14-4 | DRW375 | BUY | BOUNDARY | H02
B06 | Стальная втулка лифта | 4 | source8-10-4.5 | 8-10-4.5 | DRW375 | BUY | NOT_MODELLED | H06
S01 | X-ring колесной оси | 6 | SEA-002-526 /QRAR04116 N7004 reference | 18.72×2.62 | DRW374/TrelleborgTable8 | BUY | INSTALLED_ENVELOPE | H03
S02 | СальникZ40 | 2 | 18-30-7 профиль/материалHOLD | 18×30×7 | DRW375 | BUY | BOUNDARY | H03
S03 | O-ring боковой крышки | 2 | SEA-002-102 | 190×1.5 | DRW374 | BUY | NOT_MODELLED | H03
S04 | O-ring фланца | 6 | SEA-002-722 | 32×1.5 | DRW374 | BUY | FREE_RING_ENVELOPE | H03
S05 | O-ring корпуса | 2 | metric16×1 | 16×1 | DRW375 | BUY | NOT_MODELLED | H03
S06 | O-ring корпуса | 2 | metric38×1.5 | 38×1.5 | DRW375 | BUY | NOT_MODELLED | H03
S07 | O-ring крышкиPRESSURE | 1 | metric110×1.5 | 110×1.5 | DRW745 | BUY | NOT_MODELLED | H03
S08 | O-ring клапана | 1 | metric6×1.5 | 6×1.5 | DRW745 | BUY | NOT_MODELLED | H03
S09 | O-ring клапана | 2 | metric3×1 | 3×1 | DRW745 | BUY | NOT_MODELLED | H03
S10 | O-ring колпачка | 1 | metric10×1.5 | 10×1.5 | DRW745 | BUY | NOT_MODELLED | H03
S11 | O-ring лифта | 2 | metric15×2.5 | 15×2.5 | DRW744 | BUY | NOT_MODELLED | H03
P01 | Тяговый двигатель | 2 | Pololu5707 99:1 HP24V | Ø25×53.8 shaft4×12.5 | https://www.pololu.com/product/5707 | BUY | MANUFACTURER_STEP | H05 монтаж НЕ совместим по текущему screen
P02 | Муфта | 2 | NBKMLR-20C-6-6 | Ø20×24 bores6/6 | NBK manufacturer | BUY | BOUNDARY | H05
P03 | Колесо | 6 | MiniCamQRW90SR/150 | Ø90 остальноеHOLD | MiniCam catalog | BUY | PHOTO_APPROX | H01
L01 | PRESSURE-крышка | 1 | DRW745/PX1 | ≈158×53×7 | DRW745 | MILL | GRAPHIC_APPROX | H03
L02 | Боковой рычаг | 2 | FSS-002-068 | ≈200межцентровое | DRW744 | MILL | GRAPHIC_APPROX | H06
L03 | Центральное звено | 1 | ASS-002-723 | ≈200межцентровое | DRW744 | MILL | GRAPHIC_APPROX | H06
L04 | Основание лифта | 1 | FAL-002-067 family | присоединенияHOLD | DRW744 | MILL | GRAPHIC_APPROX | H06
L05 | Кронштейн камеры | 1 | PX1/source interface | HOLD | DRW752 | MILL | GRAPHIC_APPROX | H06 H08
L06 | Газовая пружина | 1 | ACEGS-12-80-V4A F1=150N candidate | Ø12/4 stroke80 bare192 | ACEGS12 catalog | BUY | BOUNDARY | H06 наконечники
L07 | Рычаг ручного зажима | 1 | FIX-002-527 family | M8 корпусHOLD | DRW744 | BUY | GRAPHIC_APPROX | H06
L08 | Ось зажима | 1 | FSS-002-089 | HOLD | DRW744 | TURN | NOT_MODELLED | H06
L09 | Шайба зажима | 1 | FSS-002-077 | HOLD | DRW744 | TURN | NOT_MODELLED | H06
L10 | Боковая ось лифта | 2 | FSS-002-075 | HOLD | DRW744 | TURN | PARTIAL | H06
L11 | Верхняя ось лифта | 2 | FSS-002-079 | HOLD | DRW744 | TURN | PARTIAL | H06
L12 | Пластина лифта | 1 | FSS-002-073 | HOLD | DRW744 | MILL | NOT_MODELLED | H06
L13 | Пластина крепления лифта | 2 | FSS-002-084 | HOLD | DRW375 | MILL | NOT_MODELLED | H06
L14 | Ось крепления лифта | 2 | FSS-002-373 | HOLD | DRW375 | TURN | NOT_MODELLED | H06
V01 | Корпус/шток клапана | 1 | FSS-001-843 family | седлоHOLD | DRW745 | TURN | GRAPHIC_APPROX | H03
V02 | Колпачок клапана | 1 | FSS-001-844 family | HOLD | DRW745 | TURN | GRAPHIC_APPROX | H03
V03 | Шарик клапана | 1 | precision ballØ4 | Ø4 | DRW745 | BUY | SPHERE | H03 седло
V04 | Пружина клапана | 1 | SPR-001-847 | k/preload/LfreeHOLD | DRW745 | BUY | NOT_MODELLED | H03
V05 | Бобышка прохода жгута | 1 | PX1/source adaptation | HOLD | DRW745 | MILL | GRAPHIC_APPROX | H03 H07
C01 | Корпус ротации камеры | 1 | CAM026 family | OD≈62.5 headL132 | ASM000/Drive photo | TURN | PHOTO_APPROX | H08
C02 | Боковая рама камеры | 1 | CAM026 family | HOLD | ASM001 | MILL | GRAPHIC_APPROX | H08
C03 | Поворотный оптический корпус | 1 | CAM026 family | HOLD | ASM001 | TURN/MILL | GRAPHIC_APPROX | H08
C04 | Окно камеры | 1 | Минеральное стекло/сапфир артикулHOLD | размерHOLD | ASM001 | BUY | ENVELOPE | H08
C05 | КамераCVBS | 1 | RunCamPHOENIX2-SL family | 19×19class 5–36V | existingWB16 /runcam.com | BUY | NOT_MODELLED | H08
C06 | Контроллер головы | 1 | WaveshareRP2040-Zero | 18×23.5class | existingWB16 /waveshare.com | BUY | NOT_MODELLED | H08
C07 | Драйверы осей головы | 2 | AdafruitDRV8871#3190 | 6.5–45V размещениеHOLD | https://www.adafruit.com/product/3190 | BUY | NOT_MODELLED | H08
C08 | МоторыPAN/ROTATE | 2 | 12VN20 точный артикулHOLD | вал/редукторHOLD | existingWB16 | BUY | NOT_MODELLED | H08
C09 | Токосъёмник | 1 | SenRingM125-06 | Ø12.5×13.5class 6circuits | existingWB16 /senring.com | BUY | NOT_MODELLED | H08
C10 | БелыеLED | 6 | CreeXPGDWT-B1-0000-00LE2 candidate | 3535 | existingWB16 | BUY | NOT_MODELLED | H08
C11 | ГотовыеMCPCB LED | 6 | Ø8мм3535 артикулHOLD | Ø8class | existingWB16 | BUY | NOT_MODELLED | H08
C12 | ДрайверLED | 2 | P4115adj module family | 29.3×15.1×9class | existingWB16 | BUY | NOT_MODELLED | H08
C13 | Датчики угла | 2 | AS5600 ready module exactHOLD | размерHOLD | existingRevPG | BUY | NOT_MODELLED | H08
C14 | Упорный игольчатый подшипник | 2 | BEA-001-893 | HOLD | CAM026ASS001919 | SOURCE_PART | NOT_MODELLED | H08
C15 | Упорная шайба | 2 | FSS-001-894 | HOLD | CAM026ASS001919 | SOURCE_PART | NOT_MODELLED | H08
C16 | Полый вал ротации | 1 | FSS-001-895 | HOLD | CAM026ASS001919 | SOURCE_PART | NOT_MODELLED | H08
C17 | Упорная шайба подшипника | 1 | BEA-001-815 | HOLD | CAM026ASS001919 | SOURCE_PART | NOT_MODELLED | H08
C18 | Втулка ротации | 1 | MSC-001-899 | HOLD | CAM026ASS001919 | SOURCE_PART | NOT_MODELLED | H08
C19 | Шестерня ротации | 1 | GEA-001-896 | HOLD | CAM026ASS001919 | SOURCE_PART | NOT_MODELLED | H08
C20 | Кольца интерфейса камеры | TBD | source metric ring family | 38×1.5 /6×1 /21×1.5 /28×1.5 | DRW752 | BUY | NOT_MODELLED | H03 H08 количество по конкретному исполнению
H01 | Локальный жгут | 1 | LAPP0028679 UNITRONIC FD P plus A | ровно6×0.25 OD5.4 Rmin≈27 | LAPP catalog | BUY | ROUTE_APPROX | H07 финальная длинаHOLD купить3м для образцов
H02 | КабельнаяSP13 | 1 | WEIPUSP1310/S6I-N | 6female cable4–6.5 | WEIPU catalog | BUY | ENVELOPE | H07
H03 | ПанельнаяSP13 | 1 | WEIPUSP1312/P6-C | 6male M13×1family | WEIPU catalog | BUY | NOT_MODELLED | H07
H04 | Гермоввод | 1 | LAPPSKINTOP53112000 | M12×1.5 cable3.5–7 SW16 | LAPP catalog | BUY | BOUNDARY | H03 H07
H05 | Панельный задний разъём | 1 | WEIPUSP1712 7contact суффиксHOLD | 6used+1NC | WEIPU catalog | BUY | ENVELOPE | H07 H10
H06 | Кабельный задний разъём | 1 | WEIPUSP1710 7contact суффиксHOLD | 6used+1NC | WEIPU catalog | BUY | NOT_MODELLED | H07 H10
H07 | Основнойtether | 1 | 6-жильный Proteus/профессиональный аналог артикулHOLD | 6copper+силовой элемент no coax длинаHOLD | USER cable stock | BUY | ENVELOPE | H07 H10
H08 | Гильза разгрузки | 1 | PX1 TAIL SLEEVE | OD24 ID20 L32 target | PX1 | TURN | ADAPTATION | H07
H09 | Конус силового элемента | 1 | PX1 TAIL CONE | 20→12 L30 target | PX1 | TURN | ADAPTATION | H07
H10 | Внутренний разъём обслуживания | 1 | 6way crimp pair артикулHOLD | 6circuits | PX1 | BUY | NOT_MODELLED | H07
E01 | Главный контроллер | 1 | WeActSTM32F446RET6CoreBoardV1.1 | 33.22×41.63×11.99 | WeAct officialGithub | BUY | MANUFACTURER_STEP | H09
E02 | Драйвер тягового мотора | 2 | Pololu2992G2 24v13 | 33.02×20.32×9.575 STEPmd31a | https://www.pololu.com/product/2992/resources | BUY | MANUFACTURER_STEP | H09 H10 текущаяревизияmd31c
E03 | ВходнойDC/DC | 1 | CinconCQB150W110S24 | 43–160Vin24V6.3A 57.9×36.8×12.7 | Cincon manufacturer | BUY | BODY_NO_PINS | H09 H10
E04 | DC/DC12V | 1 | Pololu5577D42V55F12 | 25.4×25.4×9 60Vmax | https://www.pololu.com/product/5577 | BUY | BOUNDARY | H09 H10
E05 | DC/DC5V | 1 | Pololu5571D42V55F5 | 25.4×25.4×9 60Vmax | https://www.pololu.com/product/5571 | BUY | BOUNDARY | H09 H10
E06 | ИзолированныйRS485 | 2 | WaveshareTTL TO RS485(C)SKU27479 | 42.8×15.2×4.75 | Waveshare manufacturer | BUY | 1_CRAWLER_BOUNDARY_1_CCU | H09 H10
E07 | Давлениеcrawler | 1 | Adafruit3965MPRLS | 17.8×16.7×7.5 0–25PSIabs | https://www.adafruit.com/product/3965 | BUY | BOUNDARY | H03 H09
E08 | Видеобалун | 2 | Delta-OptiTR-1D*P2 | 43×16×15class 2блока=1пара | existingWB16 /DeltaOpti | BUY | 1_CRAWLER_BOUNDARY_1_CCU | H07 H09
E09 | Входной электролит | 1 | NichiconUCS2D221MHD1TN | 220uF200V Ø18×25 | existingCurrent/NichiconUCS | BUY | BODY_NO_LEADS | H09 H10
E10 | ВходнойHVпредохранитель | 1 | DCrated артикул/номиналHOLD | HOLD | PX1 | BUY | NOT_MODELLED | H10
E11 | Защита ветвей моторов | 2 | DCfuse/eFuse артикул/номиналHOLD | HOLD | PX1 | BUY | NOT_MODELLED | H10
E12 | Защита камеры | 1 | DCfuse/eFuse артикул/номиналHOLD | HOLD | PX1 | BUY | NOT_MODELLED | H10
E13 | Конденсатор у драйвера | 2 | lowESR63V ёмкость/артикулHOLD | HOLD | Pololu installation guidance | BUY | NOT_MODELLED | H10
E14 | Защита рекуперации24V | 1 | ready brake shunt артикулHOLD | HOLD | PX1 | BUY | NOT_MODELLED | H10
E15 | Измерение тока | 2 | INA226 ready module шунт/артикулHOLD | HOLD | existingCurrent | BUY | NOT_MODELLED | H09 H10
E16 | ИсточникCCU | 1 | isolated100–120VDC модельHOLD | HOLD | existingCurrent | BUY | NOT_MODELLED | H10
E17 | Датчик влаги | 1 | электроды+ready module артикулHOLD | HOLD | existingCurrent | BUY | NOT_MODELLED | H09 H10
E18 | Крепёж плат/изоляция/теплоотвод | TBD | стойки/термопрокладкиHOLD | HOLD | PX1 | BUY | NOT_MODELLED | H09
E19 | Подтяжки SLP/FLT | 4 | Резистор4.7kΩ выводной артикулHOLD | 4.7kΩ номинал проектный | ELECTRICAL_Current | BUY | NOT_MODELLED | H09
F01 | M3×8 button | 24 | FIX-000-359 | M3×8 | DRW374 12per side | BUY | NOT_MODELLED | H02
F02 | M3×6 button | 24 | FIX-002-738 | M3×6 | DRW374 12per side | BUY | NOT_MODELLED | H02
F03 | Circlip12×1 | 8 | FIX-002-549family | 12×1 | DRW3746+DRW3752 | BUY | NOT_MODELLED | H02
F04 | Key4×4×12 | 6 | MSC-002-705 | 4×4×12 | DRW374 | BUY | MODELLED | H02
F05 | Key4×4×7 | 2 | FSS-002-735 | 4×4×7 | DRW374 | BUY | NOT_MODELLED | H04
F06 | M3×10 countersunk | 8 | ISO10642family | M3×10 | DRW386 | BUY | NOT_MODELLED | H05
F07 | M5×30+springwasher | 1 | standard family | M5×30 | DRW386 | BUY | NOT_MODELLED | H05
F08 | M8×16+springwasher | 2 | standard family | M8×16 | DRW375 | BUY | NOT_MODELLED | H06
F09 | M3×6 countersunk | 6 | standard family | M3×6 | DRW375 | BUY | NOT_MODELLED | H02
F10 | Belleville washer | 3 | source washer | 20×10.2×1.1 | DRW744 | BUY | NOT_MODELLED | H06
F11 | PinM6×18 | 1 | source pin | M6×18 | DRW744 | BUY | NOT_MODELLED | H06
F12 | M4×8 button | 6 | standard family | M4×8 | DRW7442+DRW7454 | BUY | NOT_MODELLED | H06
F13 | M4×12cap | 4 | standard family | M4×12 | DRW744 | BUY | NOT_MODELLED | H06
F14 | Circlip8×0.8 | 4 | standard family | 8×0.8 | DRW744 | BUY | NOT_MODELLED | H06
F15 | M10thin nut | 2 | ISO4035M10 | M10 | DRW744 | BUY | NOT_MODELLED | H06
F16 | Circlip6×0.7 | 1 | standard family | 6×0.7 | DRW744 | BUY | NOT_MODELLED | H06
F17 | Shim | 2 | source shim | 8×12×0.4 | DRW744 | BUY | NOT_MODELLED | H06
F18 | Shim | 2 | source shim | 8×12×0.25 | DRW744 | BUY | NOT_MODELLED | H06
F19 | M3×16 button | 2 | standard family | M3×16 | DRW745 | BUY | NOT_MODELLED | H03
F20 | M3×8 countersunk | 2 | standard family | M3×8 | DRW745 | BUY | NOT_MODELLED | H03
F21 | Gas spring washer | 2 | source washer | HOLD | DRW744 | BUY | NOT_MODELLED | H06
F22 | Wheelquick-lock | 6 | OEMQRWmechanism | HOLD | MiniCamcatalog | BUY | PROXY_BOLT_ONLY | H01 комплектколесаP03
PR01 | Защита жгута для примерки | 1 | PX1_Lift_Harness_Guard_PROTOTYPE.stl | OD9 ID6.4 L12 | currentmaster | PRINT | DESIGN | FIT_CHECK_ONLY
PR02 | Макет держателя моторов | 1 | PX1_Motor_Holder_FitCheck_ONLY.stl | 52.8×30×3 | M08 | PRINT | DESIGN | FIT_CHECK_ONLY
PR03 | МакетPRESSUREкрышки | 1 | PX1_PRESSURE_Cover_FitCheck_ONLY.stl | 158×53×7 | L01 | PRINT | DESIGN | FIT_CHECK_ONLY
PR04 | Макет боковой крышки | 1 | PX1_Side_Cover_FitCheck_ONLY.stl | 262×60×7 | M02 | PRINT | DESIGN | FIT_CHECK_ONLY

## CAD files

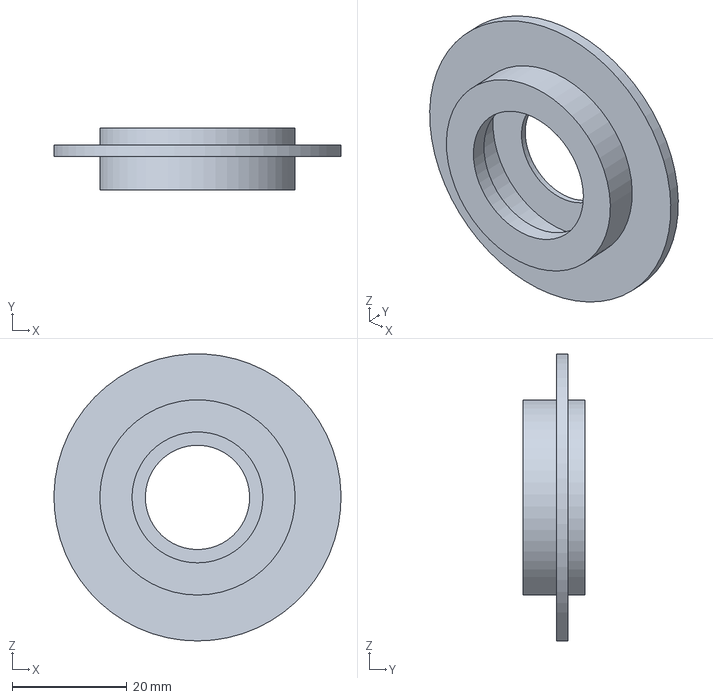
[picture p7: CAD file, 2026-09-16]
current/CAD/Metal_HOLD/HOLD_AXLE_FLANGE_-1_250.0_GRAPHIC_CONTOUR.step
50.0 x 10.8 x 50.0 mm

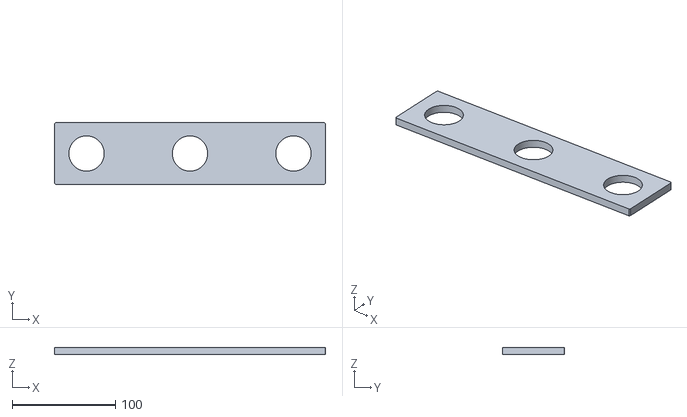
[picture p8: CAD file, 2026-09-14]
current/CAD/Print_STL/PX1_Side_Cover_FitCheck_ONLY.stl
262.0 x 60.0 x 7.00

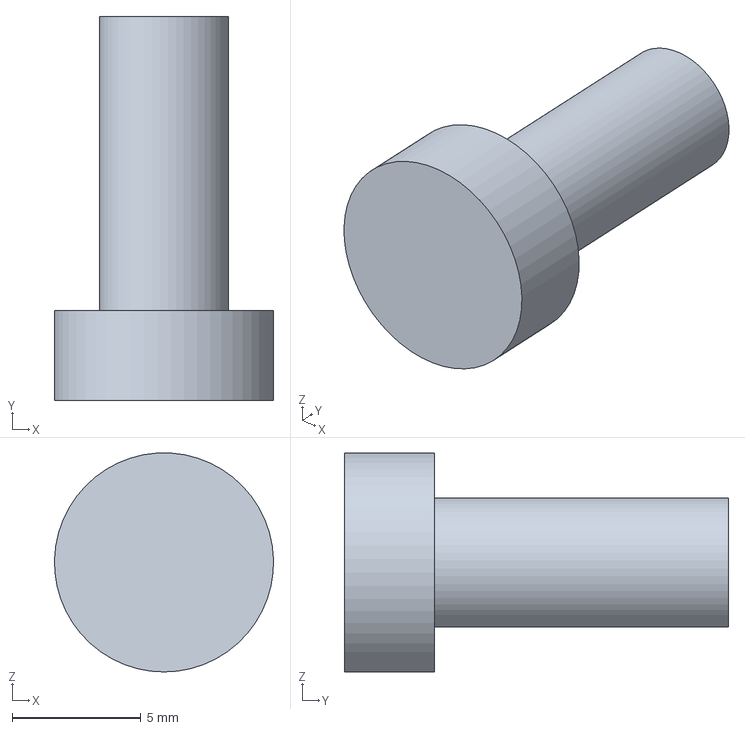
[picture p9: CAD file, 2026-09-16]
current/CAD/Metal_HOLD/HOLD_WHEEL_RETENTION_M5_-1_250.0_QUICKLOCK_UNRESOLVED.step
8.50 x 14.9 x 8.49 mm

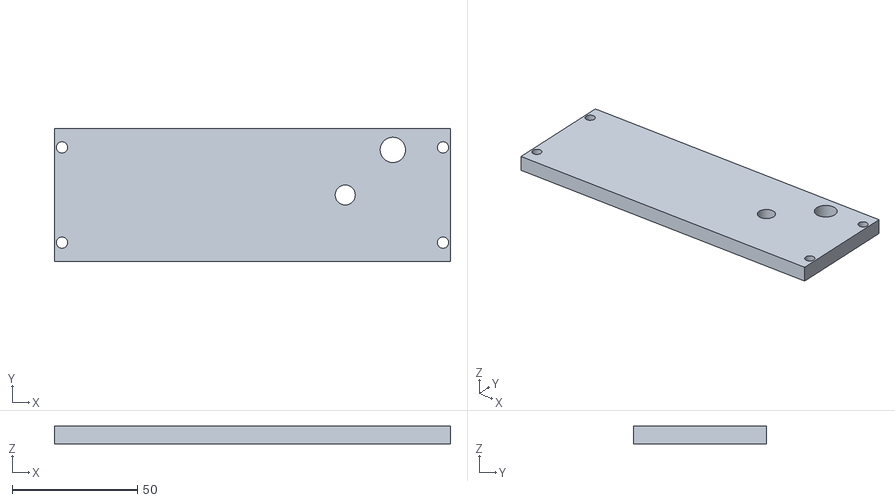
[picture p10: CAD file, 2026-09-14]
current/CAD/Print_STL/PX1_PRESSURE_Cover_FitCheck_ONLY.stl
158.0 x 53.0 x 7.00

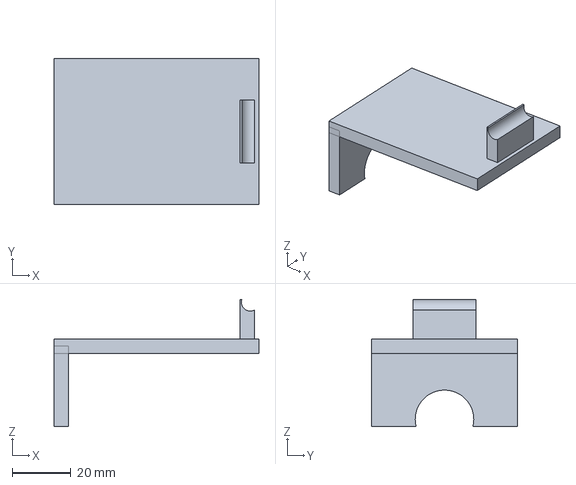
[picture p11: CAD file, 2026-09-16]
current/CAD/Metal_HOLD/HOLD_LIFT_CAMERA_CARRIER_SOURCE_INTERFACE_UNKNOWN.step
70.0 x 50.0 x 43.5 mm

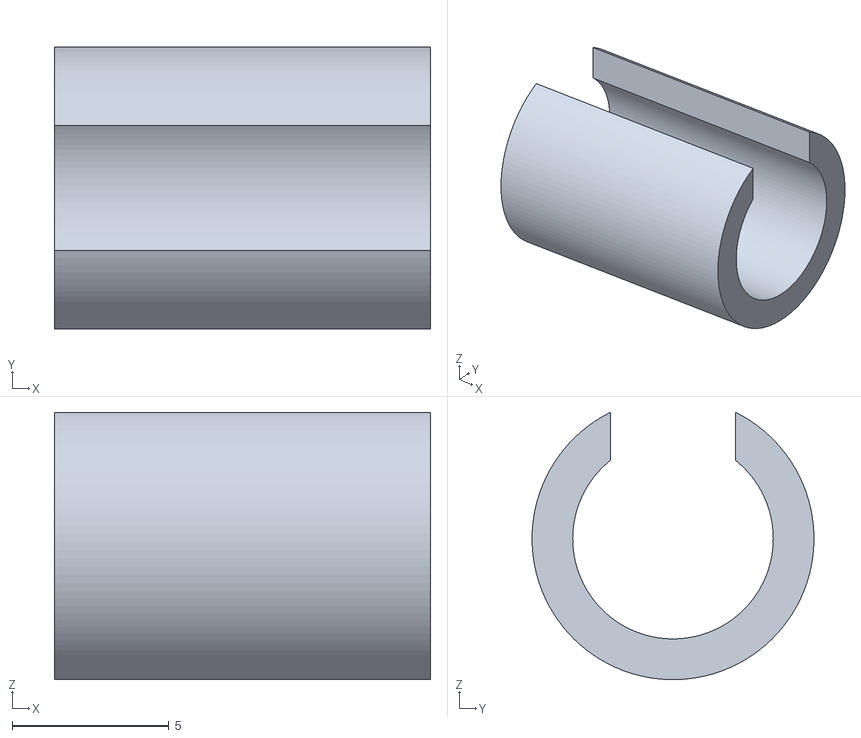
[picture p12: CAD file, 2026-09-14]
current/CAD/Print_STL/PX1_Lift_Harness_Guard_PROTOTYPE.stl
12.0 x 9.00 x 8.53

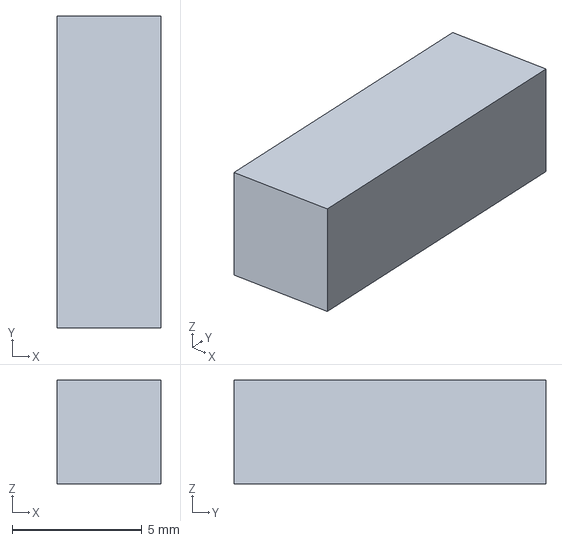
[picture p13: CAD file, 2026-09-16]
current/CAD/Metal_HOLD/KEY_4x4x12_-1_50.0.step
4.00 x 12.0 x 4.00 mm

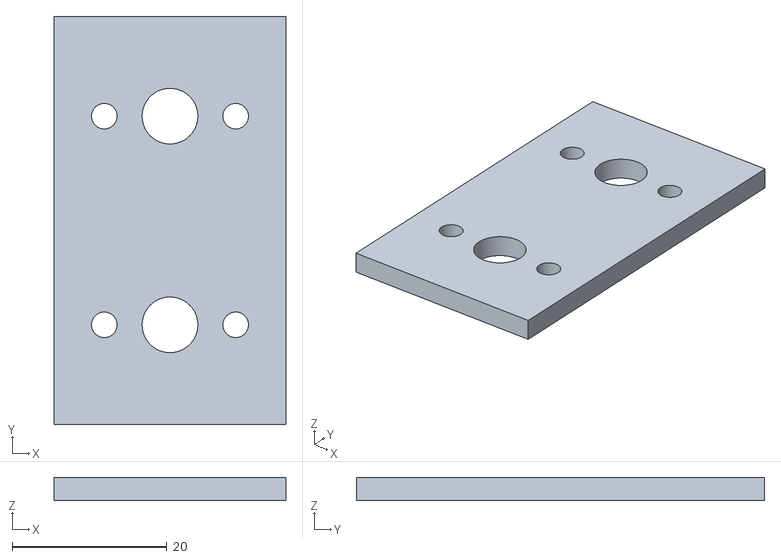
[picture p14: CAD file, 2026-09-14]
current/CAD/Print_STL/PX1_Motor_Holder_FitCheck_ONLY.stl
30.0 x 52.8 x 3.00

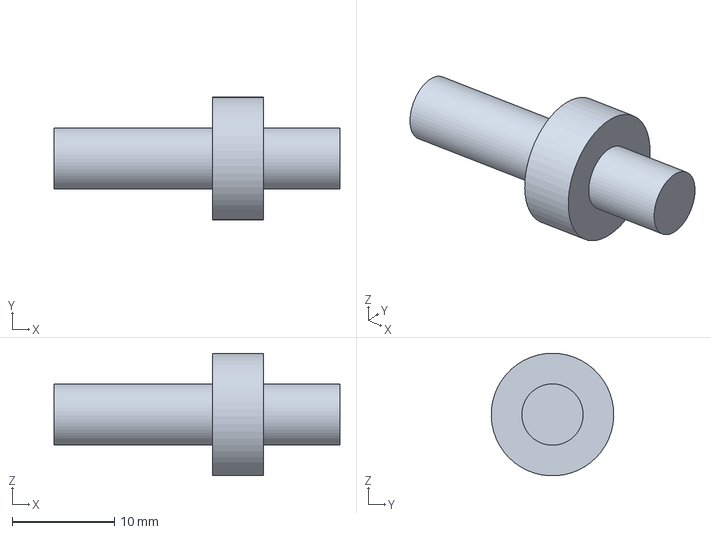
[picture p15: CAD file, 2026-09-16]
current/CAD/Metal_HOLD/HOLD_Z16_SHAFT_-1.step
28.0 x 12.0 x 12.0 mm

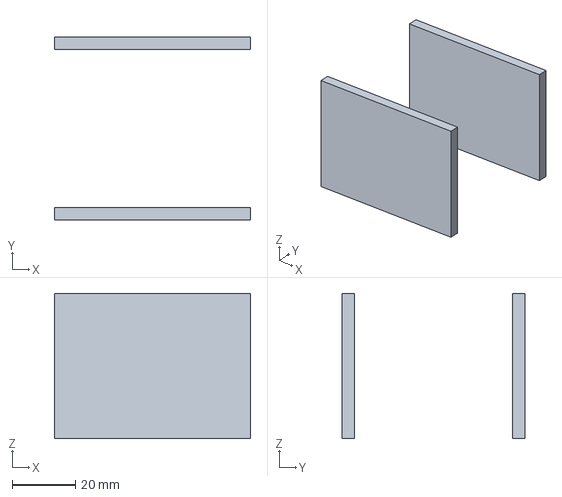
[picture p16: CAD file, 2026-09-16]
current/CAD/Metal_HOLD/HOLD_CAM026_SIDE_FRAME_GRAPHIC.step
62.0 x 58.0 x 46.0 mm

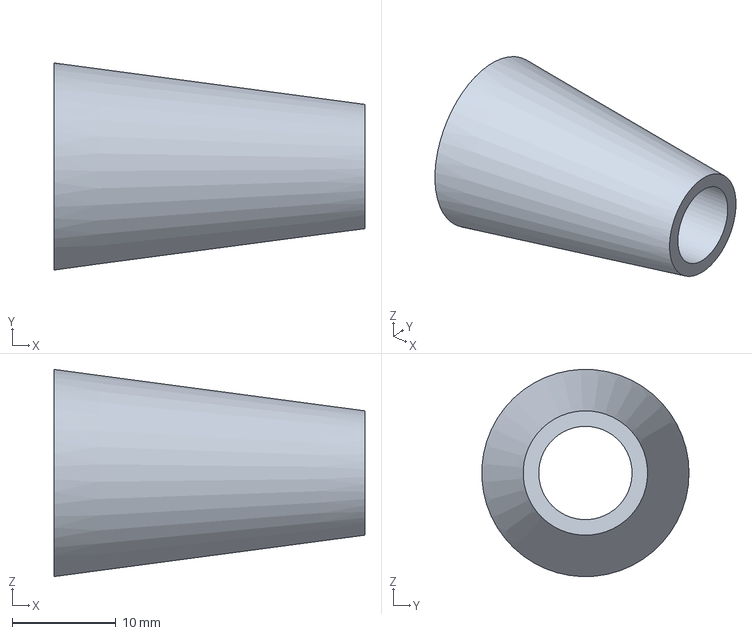
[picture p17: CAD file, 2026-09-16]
current/CAD/Metal_HOLD/HOLD_REAR_TETHER_ARAMID_CONE.step
30.0 x 20.0 x 20.0 mm

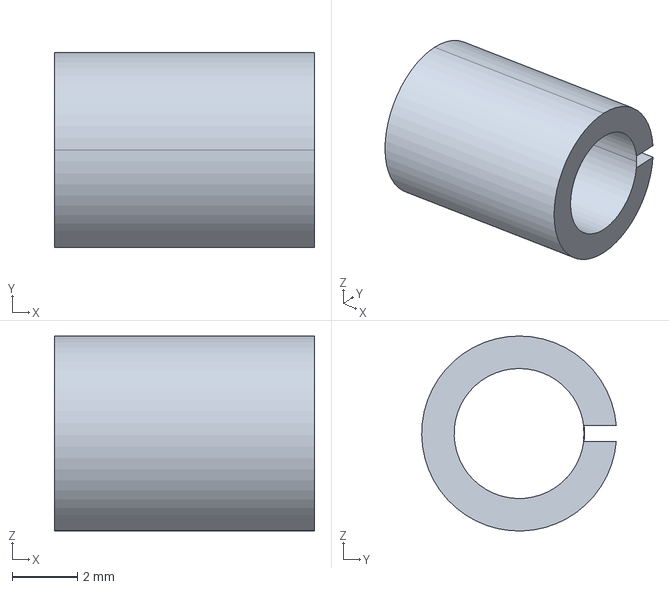
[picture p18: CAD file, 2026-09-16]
current/CAD/Metal_HOLD/HOLD_MOTOR_SPLIT_ADAPTER_6_TO_4_-1.step
8.00 x 5.99 x 6.00 mm

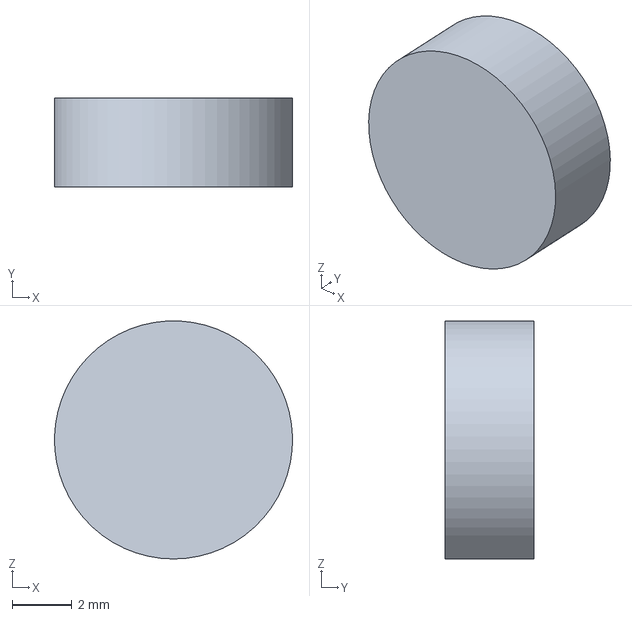
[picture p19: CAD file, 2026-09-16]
current/CAD/Metal_HOLD/HOLD_LIFT_SIDE_PIN_-1_40.step
8.00 x 3.00 x 7.99 mm

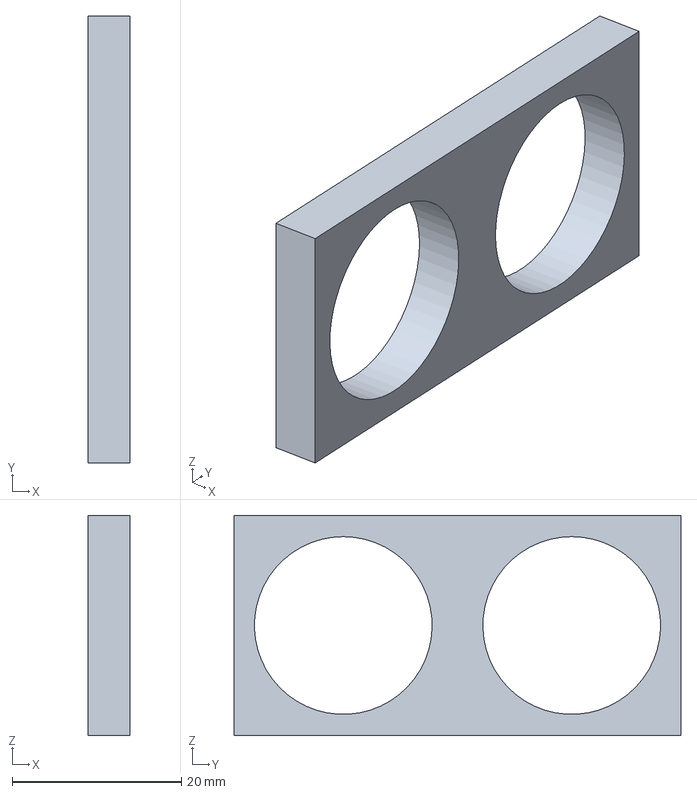
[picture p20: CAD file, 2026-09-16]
current/CAD/Metal_HOLD/HOLD_PAIRED_PINION_BEARING_HOLDER.step
5.00 x 52.8 x 26.0 mm

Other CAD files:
current/CAD/Metal_HOLD/HOLD_PRESSURE_ELECTRONICS_COVER_GRAPHIC158x53x7.step
current/CAD/Metal_HOLD/HOLD_SIDE_COVER_-1_GRAPHIC262x60x7.step
current/CAD/Metal_HOLD/HOLD_LIFT_SIDE_PIN_-1_240.step
current/CAD/Metal_HOLD/HOLD_AXLE_FLANGE_-1_150.0_GRAPHIC_CONTOUR.step
current/CAD/Metal_HOLD/HOLD_AXLE_FLANGE_-1_50.0_GRAPHIC_CONTOUR.step
current/CAD/Metal_HOLD/HOLD_CAM026_FRONT_WINDOW_DIAMETER_UNKNOWN.step
current/CAD/Metal_HOLD/HOLD_CAM026_OPTICAL_HOUSING_GRAPHIC.step
current/CAD/Metal_HOLD/HOLD_CAM026_ROTATE_HOUSING_GRAPHIC_OD62p5.step
current/CAD/Metal_HOLD/HOLD_IDLE_PIN_-1_100.0.step
current/CAD/Metal_HOLD/HOLD_IDLE_PIN_-1_200.0.step
current/CAD/Metal_HOLD/HOLD_LIFT_BASE_ON_REMOVABLE_PRESSURE_COVER.step
current/CAD/Metal_HOLD/HOLD_LIFT_CENTRAL_LEVER_ASS002723_GRAPHIC200.step
current/CAD/Metal_HOLD/HOLD_LIFT_SIDE_ARM_-1_GRAPHIC200.step
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

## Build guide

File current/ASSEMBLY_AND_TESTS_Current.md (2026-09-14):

# PX1 Current — сборка, герметизация и испытания

Статус: HOLD. Эти последовательности задают порядок работ после закрытия соответствующих посадок. Они не отменяют обнаруженные пересечения. Неизвестные размеры обозначены в реестре; замеры пользователю не поручаются.

## Два герметичных объёма

Crawler: сухой корпус, статические кольца боковых крышек 190×1.5, кольца фланцев 32×1.5, шесть X-ring валов 18.72×2.62. PRESSURE-крышка имеет кольцо 110×1.5. Верхний PRESSURE/LIFT снимается целиком. Два сальника 18×30×7 находятся на выходных валах Z40. Они могут разделять внутренние полости: выравнивание давления через реальные каналы ещё необходимо подтвердить.

Камера имеет собственный сухой объём и собственные статические и поворотные уплотнения. Разделка шести жил, вставки SP13 и гермоввод не должны создавать продольный канал для воды между камерой и crawler. Полная механика этих границ остаётся H03/H08.

Схема давления: регулируемый источник → контрольный манометр → шариковый клапан PRESSURE → сухой объём crawler → MPRLS. Камеру наполняют и контролируют отдельно через её сервисный интерфейс, который ещё не выпущен. Клапан наполнения не считается предохранительным клапаном.

MPRLS измеряет абсолютное давление: p_изб = p_abs − p_атм. Атмосферную базу записывают до закрытия и сохраняют вместе с температурой. Перезапуск под давлением не обнуляет базу. Диапазон 0–25 PSI absolute позволяет измерять примерно до 0.7 bar избыточного при обычной атмосфере, а не до 1 bar избыточного. Рабочее и испытательное давления PX1 не назначены. Паспортные 1 bar оригинального Proteus не переносятся на реконструкцию.

## Порядок сборки

1. Сверить текущую BOM, исполнение деталей и размерные источники. Очистить полости, удалить заусенцы, проверить уплотняющие поверхности.
2. Собрать каждый борт: один 61801, три 61903, две втулки 10-12-4, три осевые Z50 и две холостые Z50. Установить шпонки и стопорные кольца по утверждённым разрезам. Не передавать усилие запрессовки через тела качения.
3. Собрать валовые пакеты. Шпоночные пазы не должны пересекать дорожку уплотнения. При надевании X-ring защитить острые кромки монтажной оправкой. Точные канавки и посадки H02/H03 ещё не выпущены.
4. Установить два Z40 с 61800 и сальниками, затем два Z16 с 61801. Вручную проверить передачу момента на задние X250, люфт и пятно контакта. Конические тела CAD не задают изготовленный профиль зубьев.
5. Установить парный держатель, двигатели и муфты после устранения H05. Текущий Pololu25D конфликтует с восстановленными средними осями; силовая сборка такого пакета невозможна.
6. Закрепить готовые платы на изолированных опорах. Выполнить теплоотвод и силовой монтаж, проверить отсутствие контакта выводов с корпусом. У Cincon в CAD нет полной модели выводов и изоляции.
7. Собрать PRESSURE-крышку, клапан и M12-ввод. Проверить проход жгута и реальные уплотняющие пояски. Установить три звена ручного лифта, осевые элементы и газовую пружину с подтверждёнными наконечниками.
8. После закрытия H08 собрать собственную электронику камеры внутри её корпуса. Соединить внешний шестижильный жгут через SP13. Закрепить оболочку и проверить весь ход лифта, а не только участок R27.
9. Установить задний разъём и разгрузку tether. Растяжение воспринимает силовой элемент; жилы имеют свободный запас. Катушку и её токосъёмник проверяют отдельно.
10. После низковольтного стенда закрыть крышки, установить колёса с реальным быстросъёмом и перейти к испытаниям.

## Разборка и обслуживание

Перед открытием обесточить систему, подтвердить разряд входного конденсатора и нулевое избыточное давление.

Колесо: очистить быстросъём, использовать 4-мм ключ согласно каталогу оригинала, удерживать ось и снимать колесо наружу. Болт M5, шайба и выборка в текущем CAD показывают условное крепление H01, а не восстановленный штатный замок.

Камера: отключить SP13 на интерфейсе, неподвижном относительно съёмной головы, освободить механическое крепление и отвести голову вперёд. Её гермокорпус для замены головы открывать не предполагается. CAD проверяет восемь дискретных положений; это не непрерывная проверка траектории.

Жгут: после обесточивания и стравливания снять PRESSURE/LIFT, отключить внутренний шестиконтактный сервисный разъём, освободить зажимы и гайку M12. Если разъём больше прохода гермоввода, его разбирают или перетерминируют. После замены повторяют проверку шести цепей, изоляции и утечки. Полная ремонтная трасса H07 ещё не подтверждена.

Мотор: снять верхний узел, отключить расположенную над мотором электронику, освободить муфту и держатель. Прямое извлечение вверх в текущей проверке блокируется. Окончательный путь наклона и выхода через проём не подтверждён; ремонтопригодность H05/H09 не объявлена.

## Последовательность испытаний

1. Проверить маркировку, паспорта, редакции плат, сопротивление обмоток и отсутствие замыканий. Зафиксировать серийные номера.
2. Без питания проверить все шесть колёс, зацепления, осевой люфт и упоры лифта. Закрыть H01–H06 до рабочего нагружения.
3. На стенде 24 V с ограничением тока и вывешенными колёсами проверить сначала 5/12 V и MCU, затем связь, затем драйверы. Проверить SLP LOW при включении, reset, потере команды и watchdog. HV на этом этапе отключён.
4. Проверить видео последовательно: прямая камера; локальный жгут и SP13; балун, tether и второй балун. Повторить с PWM тяги, PAN/ROTATE и LED. Демолиния 40 м и последующее увеличение до 100–150 м требуют отдельных проверок.
5. Постепенно увеличивать нагрузку, фиксируя ток, тягу и температуру. Не использовать stall 29 kgf·cm как рабочий момент. Предел редуктора 4 kgf·cm при принятом КПД 0.85 и R45 даёт около 37 N суммарной расчётной тяги. Сопротивление реального tether этим не доказано.
6. Проверять HV только после выбора кабеля, разъёмов, DC-защиты и изоляционных зазоров. Проверить аппаратное отключение и разряд. CAD не подтверждает электробезопасность.
7. Испытывать герметичность сначала отдельных крышек, вводов и камеры, затем собранного crawler. Давление, методику и критерии назначают после проверки прочности и уплотнений. До H03 испытательное давление PX1 не задано.
8. Проверить проход в реальной трубе с внутренним диаметром 150 мм: камера внизу, весь жгут, ручка и хвост установлены. Сначала ручной проход, затем ходовой. Учесть стыки, овальность и загрязнение.
9. Целевой прототипный тест — 500 циклов ручного лифта с последующим осмотром оболочки, разделки и повторной проверкой герметичности. Это план, не выполненное ресурсное испытание.

## Изготовление

Четыре STL предназначены для примерки на Anycubic Chiron с областью 400×400×450 мм. Крышки и моторную плиту печатать плоской стороной. PETG, слой 0.2 мм и четыре периметра — начальная настройка для макета. Печатные крышки не испытывать давлением и не считать рабочими деталями гермокорпуса.

Отдельные STEP в Metal_HOLD получены из единого master и сохраняют координаты сборки. Размеры на листах показывают габарит CAD, но не заменяют посадки, шероховатость, материал и термообработку. Рабочие металлические детали к изготовлению не выпущены.

BOM содержит подтверждённые типоразмеры, реальные OEM/покупные коды и явно обозначенные неизвестные позиции. PR-макеты не добавляются к рабочему комплекту. Быстросъём F22 относится к комплекту колеса P03; его не следует автоматически заказывать второй раз.

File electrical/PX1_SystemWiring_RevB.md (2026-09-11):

# PX-1 SYSTEM WIRING — Rev.B

Date: 2026-09-11
Status: ACTIVE REV.B END-TO-END ELECTRICAL BASELINE
Supersedes `PX1_SystemWiring_RevPP.md` where exact tether construction, source voltage, converter selection or 24 V protection differs.

## 1. System chain

```text
AC / external CCU supply
        |
        v
PX1 CCU
  low-voltage controls / display / OSD
  isolated RS-485 master interface
  balanced-video receiver
  120 VDC-class crawler supply
  current-limited soft start
  hardware E-STOP disconnect
        |
        v
PX1 MANUAL REEL
  6 functional tether circuits through qualified slip ring
  local payout encoder A/B -> CCU only
        |
        v
ONE reinforced 6-functional-core tether
  22AWG HV+
  22AWG HV-
  24AWG RS485_A/B pair
  24AWG VIDEO+/- pair
  aramid tensile reinforcement
        |
        v
PX1 CRAWLER TAIL
  jacket support
  aramid structural termination
  relaxed copper service loop
  sealed 6-pin H-D 1.6 connector
        |
        v
CRAWLER HV INPUT
  3.15A time-delay HV fuse candidate
  qualified inrush limiter / controlled source ramp
  220uF / 200V input capacitor
  commercial isolated HV->24V converter
        |
        v
24 V MAIN BUS / STAR
  bus-voltage ADC
  LEFT traction branch
  RIGHT traction branch
  24->12 V camera/axis branch
  24->5 V logic/communications branch
  lighting constant-current branch
```

## 2. Main tether — active Rev.B construction

Replacement-cable target:
- exactly 6 functional copper conductors;
- 2 x 22 AWG for HV power;
- 2 x 2 x 24 AWG differential signal pairs;
- aramid/Kevlar-class strength member;
- no coax;
- no fibre;
- no additional electrical core required for shield/drain;
- target OD <=8.0 mm, absolute prototype gate <=8.5 mm;
- target mass <=60 g/m;
- breaking load >=1.5 kN, >=3 kN preferred.

First 40 m demonstrator may use the existing professional Proteus-class cable only after measurement/qualification.

## 3. Tether pinout

| Pin | Function | Replacement conductor |
|---:|---|---|
| 1 | HV+ | 22 AWG |
| 2 | RS485_A | 24 AWG pair A |
| 3 | RS485_B | 24 AWG pair A |
| 4 | HV- | 22 AWG |
| 5 | VIDEO- | 24 AWG pair B |
| 6 | VIDEO+ | 24 AWG pair B |

Gold H-D 1.6 contacts for the 22/24AWG replacement cable:
- crawler male: LAPP 13162500;
- cable female: LAPP 13163500;
- 0.14...0.37 mm²;
- strip 8 mm.

Exact contact barrel for the existing Proteus cable remains sample-driven.

## 4. Tether voltage

Active long-run source target: approximately 120 VDC, within the already approved 100-120 VDC system class.

Reason:
- lightweight 22 AWG power conductors are compatible with ~1 A cable current;
- 40 m and 100 m have good margin;
- 150 m remains feasible if normal crawler power is kept around <=100 W and higher power is short-duration only.

The 48 V and 60 V long-cable studies are historical and no longer control the active design.

## 5. Crawler HV input sequence

```text
sealed H-D connector
 -> local HV fuse
 -> inrush element / source-ramp interaction
 -> 220uF 200V bulk capacitor
 -> isolated 120V-class to 24V DC/DC
 -> 24V bus
```

Current primary engineering converter:
- Cincon CQB150W-110S24;
- 43-160 VDC input;
- 24 V / 6.3 A;
- ~151 W;
- ~57.9 x 36.8 x 12.7 mm;
- isolated.

### Procurement restriction note
The Cincon module is the current **engineering reference** because its controlled datasheet and current distributor inventory are verified. It is not considered procurement-frozen under the project's earlier `ChipDip / marketplace` sourcing restriction until an approved purchasing route is confirmed.

ChipDip's current technical library includes electrically compatible 150 W / 24 V / high-input modules, including:
- Murata `Q-24/6.25-W80` / IRQ-W80 family, 16-160 V input, 24 V / 6.25 A, ~61.21 x 39.62 x 13 mm;
- RECOM `RPA150Q-11024SRUW/P`, 14.4-170 V, 24 V / 6.25 A, but that RECOM article is now an EOL/obsolete risk and is not selected as the new freeze.

Before purchase, WB07 must be closed with an article actually available through an approved source. Electrical/CAD architecture is not changed by choosing an equivalent quarter-brick in this envelope.

## 6. HV input capacitor

Engineering candidate:
- Nichicon UCS2D221MHD1TN;
- 220 uF / 200 V;
- ~18 x 25 mm;
- mount horizontally;
- mechanically clamped.

Stored energy at 120 V is ~1.58 J. Inrush and discharge handling are mandatory.

## 7. HV input fuse

Prototype class:
- 3.15 A time-delay;
- 5 x 20 mm ceramic;
- DC rating comfortably above 120 V;
- internal dry service holder.

Current engineering article: Eaton Bussmann S505H-3.15-R class.

Final article/source is frozen together with the selected HV converter purchasing route.

## 8. 24 V main bus

The isolated converter output powers the local 24 V bus.

Normal total-output target:
- <=100 W.

Short controlled transient:
- 120...145 W class after thermal/long-line qualification.

Continuous 150 W through a hot 150 m lightweight tether is explicitly not the normal design condition.

Distribution rule:
- use one explicit 24 V star point immediately downstream of the main DC/DC;
- traction, 12 V converter, 5 V converter and lighting branch leave this star separately;
- aluminum structure is not a normal current return conductor.

## 9. Traction branches

Two branches only:

```text
24V BUS
  |
  +-- LEFT branch -> current sensor -> local bulk/TVS -> BTS7960 module -> LEFT motor
  |
  +-- RIGHT branch -> current sensor -> local bulk/TVS -> BTS7960 module -> RIGHT motor
```

Per branch Rev.B hardware:
- one 1000 uF / 50 V Nichicon UHE1H102MHD6 close to driver;
- one Littelfuse 1.5KE30A TVS directly at driver power terminals;
- verify/add ~470 nF low-inductance local decoupling;
- branch fuse value HOLD until motor bench measurements;
- external calibrated current measurement required.

## 10. Traction-driver status

BTS7960 / IBT-2 remains the approved Rev.B prototype H-bridge only.

Important:
- original Infineon BTS7960 silicon is obsolete;
- marketplace module build quality is not controlled;
- hardware current limit is far above the safe mechanical drivetrain current;
- native IS current sense is not accurate enough to be the sole precision torque sensor.

Rev.C must qualify a controlled-source driver or migrate to a current production bridge without changing mechanical drive architecture.

## 11. Traction motion policy

Normal stop:
`PWM ramp down -> INH/enable low -> COAST`.

Direction change:
`drive -> ramp down -> coast -> zero-current confirmation -> opposite direction`.

Hard instant reversal is prohibited.
Routine dynamic braking is not released.

Starting bus thresholds:
- >26.5 V: ramp toward zero / warning;
- >=27.0 V: immediate traction inhibit + latched fault;
- re-enable below 25.5 V only after stable delay and deliberate command.

## 12. 24 V bus telemetry

STM32 ADC divider candidate:
- 100 kOhm top;
- 6.8 kOhm bottom;
- 100 nF ADC filter;
- ~1.53 V at 24 V bus;
- ~2.87 V at 45 V bus.

This measurement is on the isolated low-voltage side and does not defeat HV isolation.

Direct tether-HV-to-MCU resistor divider remains prohibited.

## 13. Current telemetry

Layer 1:
- BTS7960 IS outputs for gross/fault diagnostics after calibration.

Layer 2:
- one external ready-made bidirectional current/power sensor per drive side;
- INA226 R010-class module is the Rev.B prototype candidate;
- sensor silicon measures 0...36 V bus class and supports programmable I2C addressing;
- two modules use I2C1 on PB8/PB9;
- calibrate every purchased module against a bench reference because generic module shunts/traces vary.

Final current/torque thresholds remain motor-test data, not catalog guesses.

## 14. Auxiliary low-voltage branches — WB09 freeze

### 12 V camera / camera-axis rail

Selected service module:
- Pololu `D42V55F12`;
- item `5577`;
- input 12...60 V;
- output fixed 12 V;
- typical continuous current class 4.5 A;
- 25.4 x 25.4 x 9 mm;
- soft-start, reverse-input, over-current and thermal protection;
- EN and PG available.

Loads:
- camera electronics;
- TILT/ROLL 12 V motor-driver branches;
- balanced-video transmitter if its final article uses 12 V.

The two current camera-axis motors have a combined stall-current screen of about 2.2 A. This is below the converter's current envelope, but motor stall is still fault-only operation.

Preliminary branch protection:
- 24 V converter-input fuse: 3.15 A time-delay;
- 12 V camera-harness fuse: 3.15 A time-delay;
- both values remain physical-test driven.

### 5 V logic rail

Selected service module:
- Pololu `D42V55F5`;
- item `5571`;
- input 5...60 V;
- output fixed 5 V;
- typical continuous current class 6 A;
- 25.4 x 25.4 x 9 mm;
- same mechanical family as the 12 V converter;
- soft-start, reverse-input, over-current and thermal protection;
- EN and PG available.

Loads:
- NUCLEO-F446RE through E5V;
- crawler-side isolated RS-485 TTL side;
- current sensors;
- low-voltage sensors/interfaces.

This converter is intentionally oversized; 60 V input rating was selected to keep margin above WB08's common 24 V bus transient envelope rather than relying on old 35/36 V hobby buck modules.

Preliminary branch protection:
- 24 V converter-input fuse: 1.0 A time-delay;
- NUCLEO E5V harness protection starting class: <=0.75 A after real-load measurement.

### NUCLEO power rule

- `5V_LOGIC -> NUCLEO E5V`;
- follow ST UM1724 external-supply jumper and USB power-sequence requirements;
- do not connect the crawler 24 V bus directly to E5V;
- other 5 V loads connect in parallel to the 5 V rail, not through the NUCLEO board.

## 15. Main RS-485 physical layer — WB09

Selected module family:
- Waveshare `TTL TO RS485 (C)`;
- SKU `27479`;
- same module at crawler and CCU ends;
- half duplex;
- isolated power and signals on-board;
- TVS/protection on-board;
- optional 120 ohm termination;
- approximately 42.8 x 15.2 x 4.75 mm;
- automatic ready-module direction handling; no external MCU DE GPIO is required.

Crawler MCU allocation:
- PC10 / USART3_TX;
- PC11 / USART3_RX;
- PA2/PA3 kept for NUCLEO ST-LINK VCP debug.

Local camera UART reservation:
- PC12 / UART5_TX;
- PD2 / UART5_RX.

### RS-485 common-mode HOLD

The tether intentionally has only A/B for RS-485 and no seventh reference conductor.

Therefore galvanic isolation is required but is not by itself proof of unlimited common-mode margin.

Rules:
- never bond isolated RS-485 line-side reference/PE to tether HV-;
- never consume VIDEO+/VIDEO- as a temporary reference in the released harness;
- do not claim 150 m production release from the Waveshare distance rating alone;
- scope/test differential and common-mode behavior at 40 m, then 100/150 m equivalent, while traction/camera motors and lighting are switching.

If common-mode margin is inadequate, revise the physical layer deliberately. Do not silently alter the six-core pinout.

Termination:
- only at the two physical tether endpoints;
- match the measured characteristic impedance of the final signal pair;
- use onboard 120 ohm only if the pair measurement justifies it;
- no termination in the reel middle.

## 16. Ground/return routing

Rules:
- motor returns use short high-current paths back to the 24 V star;
- LEFT motor return does not flow through RIGHT current sensor;
- camera/video/logic return does not carry traction motor current;
- balanced-video and RS-485 pair routing remains physically separated from BTS7960 switching loops;
- auxiliary buck heat and traction-driver heat are coupled to the aluminum body/carrier where practical, not stagnant air only;
- RS-485 TTL-side ground belongs to logic ground while line side remains galvanically isolated.

## 17. Hardware safety

CCU hardware E-STOP must disable tether HV independently of the crawler MCU.

Crawler firmware cannot override:
- open E-STOP chain;
- source overcurrent;
- line/connector safety fault.

On lost command/heartbeat:
- traction INH low;
- motor coast;
- camera-axis commands stop;
- CCU subsequently removes HV according to fault policy.

No disconnected tether connector may remain energized.

## 18. Bring-up sequence

1. 24 V bench crawler only.
2. Verify 12 V and 5 V rails on dummy loads.
3. Power NUCLEO through E5V and verify USB/ST-LINK power sequencing.
4. One motor side at a time: motor -> supported bevel -> side drive.
5. Calibrate current versus torque and calibrate both INA226-class modules.
6. Add second traction side and bus transient logging.
7. Prove isolated RS-485 and balanced CVBS at low voltage through 40 m.
8. Exercise RS-485 common-mode/noise with traction, camera axes and LED PWM active.
9. Build HV converter carrier/harness on dummy load.
10. Qualify inrush, fuse and E-STOP without crawler attached.
11. Integrate crawler at 40 m.
12. Emulate 100/150 m loop resistance and repeat RS-485 common-mode tests.
13. Only then order/operate long tether.

## 19. Controlled document references

- `tether/REVB_WB06_TETHER_POWER_SIGNAL_FREEZE.md`
- `mechanical/REVB_WB05_TAIL_CONNECTOR_AND_STRAIN_RELIEF.md`
- `electronics/REVB_WB07_HV_TO_24V_POWER_STAGE.md`
- `electronics/REVB_WB08_24V_BUS_REGEN_PROTECTION.md`
- `electrical/REVB_WB09_LOW_VOLTAGE_COMMS.md`
- `electrical/PX1_CommonServiceModules_RevB.md`
- `electrical/REV_B_WB09_VALIDATION.json`
- `mechanical/REVB_WB03_BEVEL_MOTOR_TORQUE_GATE.md`
- `firmware/crawler/board_map_f446.h`

## Change log

### 2026-09-11 — Rev.B promotion
- promoted 120 V long-tether architecture;
- promoted 22/24 AWG six-functional-core replacement tether;
- promoted sealed H-D 1.6 tail connector architecture;
- added 150 W-class 120V->24V quarter-brick stage;
- added 24 V regenerative/transient protection and coast-stop policy;
- recorded BTS7960 lifecycle/current-sense limitations;
- explicitly restored the approved-source procurement gate for the HV DC/DC rather than treating DigiKey/Mouser availability alone as final procurement approval.

### 2026-09-11 — WB09 integration
- froze Pololu 5577 as the 12 V camera/axis converter and Pololu 5571 as the 5 V logic converter for Rev.B;
- replaced old 35/36 V-class auxiliary-buck assumptions with 60 V-input modules;
- fixed NUCLEO power at regulated E5V;
- froze Waveshare 27479 as the Rev.B isolated ready-made RS-485 module family;
- moved main tether UART to USART3 PC10/PC11 and removed the external DE requirement;
- reserved UART5 PC12/PD2 for the local camera node and I2C1 PB8/PB9 for current sensors;
- recorded two-wire/no-reference RS-485 common-mode behavior as a physical qualification HOLD.

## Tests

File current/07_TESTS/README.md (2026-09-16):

# 07 TESTS

No engineering PASS is granted by CAD export alone.

Required test ladder:
- A0 drivetrain no-load/load run;
- A1 straight/reverse/turn and DN150 physical fit;
- A2 40 m tether loaded voltage + communication test;
- A3 video/light/lift-cycle test with traction motors running;
- A4 integrated demonstration run;
- A5 pressure decay/submersion, thermal and endurance tests.

Record actual measured values, failures and fixes. A failed test changes the design only as much as needed to remove the verified failure.

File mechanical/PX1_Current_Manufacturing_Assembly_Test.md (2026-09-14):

# PX1 Manufacturing / Assembly / Test - Current

## A. Manufacture / buy now

The following standard/published items can be ordered now for prototype build and physical closure:
- 14 x 61801-2RS;
- 6 x 61903-2RS;
- 2 x 61800-2RS;
- X-ring 18.72x2.62 samples;
- 18x30x7 rotary shaft-seal samples;
- 2 x ISL PGM-32P-24-100-60-02 traction motors (+ spare recommended);
- 2 x NBK MLR-20C-6-6 couplings (+ spare recommended);
- LAPP 53112000 gland;
- STM32 NUCLEO-F446RE;
- Cincon CQB150W-110S24;
- Adafruit MPRLS Product 3965;
- Nichicon UCS2D221MHD1TN;
- selected WEIPU SP13 camera connector pair and SP17 rear connector samples;
- exact BTS7960/IBT-2 ready modules for dimensional closure.

## B. Final machining HOLD

Do **not** final-machine the following until their listed gates close:
- main pressure body / side-cover interfaces;
- wheel shafts and exact 61801 shoulder stack;
- side covers / seal grooves;
- Z16/Z40 matched bevel pair and mounting distances;
- final camera housing and internal pan stack;
- final rear tether strain-relief / aramid termination.

The CAM026 teardown now supplies a real camera architecture reference and an approximately 62.5 mm base OD, but internal wall thickness, bearing fits, ring-gear tooth geometry and seal grooves remain HOLD. No further user teardown measurements are required; close those values with controlled drawings, supplier samples or prototype work.

## C. 3D-print list - Anycubic Chiron

Current printable parts are fit/protection prototypes only:
- `PX1_Lift_Harness_Guard_PROTOTYPE.stl`;
- `PX1_PRESSURE_Cover_FitCheck_ONLY.stl`;
- `PX1_Rear_SP17_FitGauge.stl`.

Use PETG/ASA for dry fit. They are not released as final pressure boundaries or drivetrain structural parts.

## D. Assembly sequence

1. Inspect, deburr and clean all metal parts; record first-article dimensions.
2. Install the two Z40 body bearing/seal paths and rear long input shafts.
3. Build each side drive with three wheel shafts, two 61801 per wheel station, five-Z50 train, 61903, X-rings and flanges; set end float/backlash only from released drawings.
4. Fit supported Z16 shafts, matched Z16/Z40 pairs, NBK couplings and two ISL motors; verify free rotation before power.
5. Fit internal power conversion, controller, MPRLS pressure sensor, communication and video modules.
6. Fit rear service cover / SP17 connector and the independent mechanical tether strength termination. Electrical contacts must carry no towing load.
7. Assemble manual lift / gas spring, short exactly-six-core camera harness and SP13 camera connection.
8. Build the separate sealed camera using the CAM026-derived architecture reference; internal geometry remains prototype-gated.
9. Pressure-test crawler without camera and camera separately; then mate the two units.
10. Install wheels last and verify retention and tool access.

## E. Test sequence

1. Hand rotation: both side trains free, no binding, all three wheels on each side rotate consistently.
2. 24 V current-limited traction bench test, unloaded then restrained-load test.
3. RS-485 watchdog, loss-of-command STOP and hardware E-STOP.
4. Local camera harness: power + TX/RX + live CVBS simultaneously while cycling the lift.
5. +0.25 bar crawler pressure decay, then submerged bubble test; repeat with pressure-valve cap removed.
6. Separate camera pressure/submersion test.
7. Rigid DN150 jig with the **real QRW90SR/150 wheel/profile**, lift LOW, service hardware installed.
8. 40 m tether test with traction, video, control and pressure telemetry simultaneously under load.
9. Dirty/wet service test and timed wheel/camera/motor replacement.
10. Only after 40 m acceptance, validate the 100-150 m electrical/tether equivalent.

## F. Current release holds

1. QRW90SR/150 exact width, tread contour, hub and quick-lock geometry; full DN150 release remains HOLD.
2. Exact axial shoulder-by-shoulder order and Y locations of the two 61801 bearings at each wheel station, including FSS-002-063/FSS-002-064 dimensions.
3. Z16/Z40 pressure angle, face width, tooth system, mounting distance, backlash and heat treatment.
4. Actual purchased BTS7960/IBT-2 board dimensions including terminal/heatsink projections.
5. Exact reinforced six-core tether article, OD and aramid termination; SP17 structural strain relief remains prototype geometry.
6. Pressure-cover groove, valve and all pressure seals require +0.25 bar decay + submerged bubble test.
7. CAM026-derived camera: ~62.5 mm base OD is confirmed, but internal fits, wall thickness and gear/seal geometry remain prototype/supplier-sample HOLD.
8. Exact six-core local camera cable article requires flex + simultaneous CVBS/TX/RX EMC testing.

No global PASS is declared while any HOLD above controls final fabrication or full DN150 release.

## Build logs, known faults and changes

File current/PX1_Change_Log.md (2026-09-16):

# PX1 — единый журнал изменений

## 16.09.2026 · Rev.A fast-track

- Rev.A окончательно зафиксирован как обязательная шестиколёсная база: X50/X150/X250, по пять Z50 на борт, задний X250 — вход привода.
- Созданы отдельные стадии A0–A6 и активная структура `current/00...09`, без изменения базовой архитектуры робота.
- A0 вынесен в отдельный стенд: реальный корпус и герметизация больше не блокируют проверку кинематики.
- По DRW374/375/386 разделены достоверные исходные данные и реконструкции. Источник подтверждает 3 приводных Z50 + 2 холостых Z50 на борт, Z40 в корпусе и двухмоторный узел с двумя Z16 и двумя 61801.
- Исправлено прежнее чрезмерное утверждение, что `MOT-001-760` обязательно является FAULHABER 2250+26/1S. FAULHABER оставлен как компактный кандидат; совместимость конкретного мотор+редуктор пакета теперь отдельный gate.
- Добавлен текущий manufacturer-supported кандидат того же класса: 2250S024BX4 + 26A. Любой 2250-путь требует BLDC-драйвера с Hall; BTS7960/Pololu G2 не могут коммутировать BX4.
- Создан генератор A1 шестиколёсного печатного ходового стенда. Он сохраняет оси и шаг шестерён, но использует временные 12-мм валы/6001 и не выдаётся за производственный гермокорпус.
- A1 CAD локально построен: общий envelope около 290×133×90 мм; side plate около 260×74×6 мм помещается на Anycubic Chiron. Профиль QRW90 остаётся H01.
- Реализован `PX1 Protocol V1` и аппаратно-независимое ядро crawler firmware: sequence guard, watchdog 250 ms, немедленный fail-safe stop, ramp обычных команд, telemetry/fault flags. Добавлены host-тесты CI.
- Текущий STEP/PDF production package по-прежнему HOLD: успешный CAD/CI не заменяет физический A0/A1 тест и испытание герметичности.

## 14.09.2026 · Rev.C

- Исправлена ошибочная трактовка позиции6DRW374: всего61801=4, не14.
- Корпус410мм, рычаги90мм и камера78мм удалены. Корпус≈278×68×64, боковые≈262×60×7, PRESSURE≈158×53×7, длинные звенья≈200 восстановлены по векторным листам и обозначены GRAPHIC_APPROX.
- Оставлены6колёс,10Z50,2Z40,2Z16,2мотора, заднийX250приводной.
- Добавлены заводские STEP Pololu25D,WeActF446 иPololu2992. ISLØ36 иNUCLEO70мм исключены. ЗаменаBTS7960 наG2вызвана размеромплаты; полнаяработоспособностьмоторов вкорпусеHOLD.
- ЛокальныйLAPP0028679ровно6жил; исключён старый7-жильный0027429. Основнойtether6жилбезкоаксиала.
- Осевыеуступы, проходжгута, крепёж и размещениенесколькихплат исправлены. Полноеустранениепересечений незаявлено.
- ВосстановленсоставлифтаDRW744:2боковыхзвена+1центральное. ACEGS12-80 —кандидатвместослишкомкороткойGS12-20.
- КамеравосстановленапотопологииASM000/ASM001;фиктивныевнутренностизамененыявнымреестромнезавершённыхпозиций.
- ПослеотключениялокальнойCADсреды исходныйcurrentвосстановленизсохранённоготекста; окончательныйэкспорт/результатдолжен подтверждатьсясборкойGitHub, анестарымvalidation.
- ДокументацияимеетHOLDстатус,условныеболванкинеполучаютPASS. Замеры пользователю не назначаются.

## 14.09.2026 · исправления по повторному CAD screen

- Перенесены DC/DC, видеобалун, контроллер и входной конденсатор для устранения выявленных пересечений. Габариты покупных компонентов сохранены.
- Исправлены осевое положение шайб/головок и условная выборка ступицы. Это эскиз крепления H01, не восстановленный заводской быстросъём.
- Уточнён зазор центрального звена/кронштейна; добавлен проход клапана и доступ к двум винтам в несущем основании лифта. Герметичная крышка не объявлена испытанной.
- Поднят M12-ввод, уточнена бобышка; динамический маршрут жгута всё ещё H07.
- Добавлены две векторные схемы и строка колец интерфейса DRW752 с неизвестным количеством. Текущая BOM:129строк.
- Дополнены четыре подтяжки SLP/FLT и уточнён предел измерения MPRLS: около0.7bar избыточного при обычной атмосфере.

## Проверка оформления текущего выпуска

Исправлено выпадение кириллицы в двух PDF-схемах: все подписи используют встроенный DejaVu Sans. Убраны одинокие строки на последних страницах; перечень HOLD сведён в таблицу. Чертежи, STEP и STL не изменялись. Геометрия: 146 объектов, 29 жёстких пересечений, ошибок Boolean нет. Производственный статус остаётся HOLD.

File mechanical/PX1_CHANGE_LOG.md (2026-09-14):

# PX1 Change Log

## 2026-09-14 - final-current rebuild

- Rejected the prior primitive-box/cylinder representation as a manufacturing release.
- Rebuilt one current assembly around the Proteus CRP-150 drivetrain topology.
- Corrected side-drive bearing quantity to **6 x 61801 per side = 12**, plus 2 x Z16 support bearings = 14 total.
- Replaced smooth Z50 discs by visible 50-tooth m1 gear solids; final tooth system remains supplier/source HOLD.
- Added complete wheel-station stacks: 2 x 61801 + 61903 + X-ring + flange + shaft at all six stations.
- Added two motor paths with the published ISL PGM-32P envelope and NBK MLR-20C-6-6 coupling envelope.
- Added manual parallelogram lift, gas spring, separate sealed camera, six-core harness, pressure cover/valve/gland, SP13 local connector and SP17 rear connector.
- Selected Adafruit MPRLS Product 3965 as the current ready-made absolute pressure sensor candidate and modeled its published envelope.
- Validation now has **no global PASS** while any placeholder/measurement HOLD controls release.
- Full DN150 remains HOLD until a real QRW90SR/150 wheel profile/hub is closed and physically tested.

### CAM026 evidence update

- Incorporated user teardown photos/video of CAM026.
- Recorded the lower/base cylindrical outer diameter as approximately **62.5 mm** from the caliper photo.
- Retired the previous ~Ø52 camera proxy.
- Preserved the observed camera architecture in current CAD: hollow central wiring path, internal ring-gear output, multi-stage reduction and thrust-bearing axial support.
- Internal CAM026 wall thickness, fits, tooth geometry and seal-groove dimensions remain HOLD. They are not inferred from photographs.
- No additional user teardown/measurement work is required; unresolved camera dimensions move to controlled-drawing / supplier-sample / prototype closure.

### Current validation snapshot

- Frozen counts match: 6 wheels, 10 Z50, 12 side-drive 61801, 6 61903, 6 X-rings, 2 Z40, 2 Z16, 2 Z16-support 61801, 2 motors, 6 local camera conductors.
- Current assembly reports no invalid CAD shapes.
- Modeled service-vs-Z50, service-vs-lift, service-vs-camera and motor-vs-camera intersections are 0 mm³.
- CAM026-derived camera LOW ideal-DN150 screen clearance is approximately 20.80 mm.
- Reconstructed pressure-body ideal-DN150 screen clearance is only approximately 1.01 mm and therefore remains a major release HOLD.

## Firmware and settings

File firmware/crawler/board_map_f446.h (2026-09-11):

#pragma once
/* PX-1 crawler / NUCLEO-F446RE / Rev.B WB10 logical pin map */

/*
 * Main tether RS-485
 * Waveshare TTL TO RS485 (C), SKU 27479, handles half-duplex direction
 * internally and exposes TXD/RXD rather than an external DE input.
 * PC10/PC11 are used so PA2/PA3 can remain on the NUCLEO ST-LINK VCP
 * for bench diagnostics.
 */
#define PX1_RS485_TX "PC10/USART3_TX"
#define PX1_RS485_RX "PC11/USART3_RX"
#define PX1_RS485_AUTO_DIR 1

/* ST-LINK VCP / bench debug */
#define PX1_DEBUG_TX "PA2/USART2_TX"
#define PX1_DEBUG_RX "PA3/USART2_RX"

/* Local crawler <-> camera-node UART; does not use tether cores */
#define PX1_CAMERA_TX "PC12/UART5_TX"
#define PX1_CAMERA_RX "PD2/UART5_RX"

/*
 * I2C1 service bus
 * Direct: LEFT/RIGHT INA226-class current sensors + TCA9548A mux.
 * TCA9548A ch0/ch1/ch2: P0/P1/P2 LPS28 pressure sensors.
 */
#define PX1_I2C_SCL "PB8/I2C1_SCL"
#define PX1_I2C_SDA "PB9/I2C1_SDA"
#define PX1_PRESSURE_MUX_ADDR 0x70
#define PX1_PRESSURE_P0_CH 0
#define PX1_PRESSURE_P1_CH 1
#define PX1_PRESSURE_P2_CH 2
#define PX1_LPS28_ADDR 0x5C

/* Traction */
#define PX1_TRACTION_L_PWM "PA8/TIM1_CH1"
#define PX1_TRACTION_R_PWM "PA9/TIM1_CH2"
#define PX1_WHEEL_L_ADC "PA0/ADC1_IN0"
#define PX1_WHEEL_R_ADC "PA1/ADC1_IN1"

/* Sensors / telemetry */
#define PX1_LEAK_ADC "PC0/ADC1_IN10"
#define PX1_LEAK_EXCITE "PB15"
#define PX1_BUS_ADC "PC1/ADC1_IN11"
#define PX1_TEMP_ADC "PC2/ADC1_IN12"

/* Camera / lighting control */
#define PX1_LIGHT_PWM "PB6/TIM4_CH1"
#define PX1_TILT_IN1 "PC6"
#define PX1_TILT_IN2 "PC7"
#define PX1_ROLL_IN1 "PC8"
#define PX1_ROLL_IN2 "PC9"

/* Safety */
#define PX1_ESTOP "PB13"
#define PX1_LEAK_DIGITAL_RESERVE "PB14"

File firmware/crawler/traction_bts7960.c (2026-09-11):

#include <stdint.h>
#include <stdbool.h>

#include "traction_bts7960.h"
#include "../common/px1_protocol.h"

extern void board_pwm_left(uint16_t duty);
extern void board_pwm_right(uint16_t duty);
extern void board_left_dir(bool forward);
extern void board_right_dir(bool forward);
extern void board_left_enable(bool en);
extern void board_right_enable(bool en);

typedef enum {
    SIDE_DRIVE = 0,
    SIDE_RAMP_TO_ZERO,
    SIDE_COAST_FOR_REVERSE
} side_state_t;

typedef struct {
    int16_t requested;
    int16_t output;
    int8_t last_motion_sign;
    int8_t pending_sign;
    side_state_t state;
    uint32_t coast_since_ms;
    uint32_t jam_since_ms;
    bool jam_timer_active;
} traction_side_t;

static traction_side_t g_left;
static traction_side_t g_right;
static uint32_t g_last_update_ms;
static uint32_t g_fault_bits;
static uint16_t g_left_jam_ma;
static uint16_t g_right_jam_ma;
static uint16_t g_jam_delay_ms;
static uint16_t g_zero_current_ma = PX1_TRACTION_ZERO_CURRENT_MA;
static bool g_outputs_enabled;

static int8_t command_sign(int16_t v)
{
    if (v > PX1_TRACTION_DEADBAND) return 1;
    if (v < -PX1_TRACTION_DEADBAND) return -1;
    return 0;
}

static uint16_t abs_i16_u16(int16_t v)
{
    int32_t x = v;
    if (x < 0) x = -x;
    if (x > 65535) x = 65535;
    return (uint16_t)x;
}

static int16_t approach_with_step(int16_t current, int16_t target, uint16_t step)
{
    int32_t c = current;
    int32_t t = target;

    if (t > c + step) return (int16_t)(c + step);
    if (t < c - step) return (int16_t)(c - step);
    return target;
}

static uint16_t slew_step_from_dt(uint32_t dt_ms)
{
    /* Prevent a delayed scheduler call from producing one large command jump. */
    if (dt_ms == 0u) dt_ms = 1u;
    if (dt_ms > 50u) dt_ms = 50u;

    uint32_t step = (PX1_TRACTION_SLEW_PER_SECOND * dt_ms + 999u) / 1000u;
    if (step < 1u) step = 1u;
    if (step > PX1_TRACTION_CMD_MAX) step = PX1_TRACTION_CMD_MAX;
    return (uint16_t)step;
}

static void apply_left(int16_t cmd)
{
    if (command_sign(cmd) == 0) {
        board_pwm_left(0u);
        board_left_enable(false);
        return;
    }

    /* Opposite polarity is reached only after a disabled COAST state. */
    board_left_dir(cmd > 0);
    board_pwm_left(abs_i16_u16(cmd));
    board_left_enable(true);
}

static void apply_right(int16_t cmd)
{
    if (command_sign(cmd) == 0) {
        board_pwm_right(0u);
        board_right_enable(false);
        return;
    }

    board_right_dir(cmd > 0);
    board_pwm_right(abs_i16_u16(cmd));
    board_right_enable(true);
}

static void disable_outputs_now(void)
{
    board_pwm_left(0u);
    board_pwm_right(0u);
    board_left_enable(false);
    board_right_enable(false);
    g_outputs_enabled = false;
}

static void reset_side_state(traction_side_t *s, uint32_t now_ms)
{
    s->requested = 0;
    s->output = 0;
    s->last_motion_sign = 0;
    s->pending_sign = 0;
    s->state = SIDE_DRIVE;
    s->coast_since_ms = now_ms;
    s->jam_since_ms = now_ms;
    s->jam_timer_active = false;
}

static void force_side_coast(traction_side_t *s, uint32_t now_ms)
{
    s->requested = 0;
    s->output = 0;
    s->pending_sign = 0;
    s->state = SIDE_COAST_FOR_REVERSE;
    s->coast_since_ms = now_ms;
    s->jam_timer_active = false;
}

void traction_init(uint32_t now_ms)
{
    reset_side_state(&g_left, now_ms);
    reset_side_state(&g_right, now_ms);
    g_last_update_ms = now_ms;
    g_fault_bits = 0u;
    g_left_jam_ma = 0u;
    g_right_jam_ma = 0u;
    g_jam_delay_ms = 0u;
    g_zero_current_ma = PX1_TRACTION_ZERO_CURRENT_MA;
    disable_outputs_now();
}

void traction_set_target(int16_t left, int16_t right)
{
    g_left.requested = px1_clamp1000(left);
    g_right.requested = px1_clamp1000(right);
}

void traction_configure_jam_limits(uint16_t left_jam_ma,
                                   uint16_t right_jam_ma,
                                   uint16_t jam_delay_ms,
                                   uint16_t zero_current_ma)
{
    g_left_jam_ma = left_jam_ma;
    g_right_jam_ma = right_jam_ma;
    g_jam_delay_ms = jam_delay_ms;
    g_zero_current_ma = zero_current_ma ? zero_current_ma : PX1_TRACTION_ZERO_CURRENT_MA;
}

static bool update_jam_detector(traction_side_t *s,
                                bool drive_active,
                                uint16_t abs_current_ma,
                                uint16_t limit_ma,
                                uint32_t now_ms)
{
    if (!drive_active || limit_ma == 0u || g_jam_delay_ms == 0u) {
        s->jam_timer_active = false;
        return false;
    }

    if (abs_current_ma < limit_ma) {
        s->jam_timer_active = false;
        return false;
    }

    if (!s->jam_timer_active) {
        s->jam_timer_active = true;
        s->jam_since_ms = now_ms;
        return false;
    }

    return (uint32_t)(now_ms - s->jam_since_ms) >= g_jam_delay_ms;
}
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

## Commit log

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2026-08-27 Add rear bearing and seal carrier FreeCAD generator
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2026-08-27 Add analytical involute spur gear generator for PX-1
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2026-08-27 Add Rev.AN rear shaft stack and correct shaft length
2026-08-27 Document Rev.AN rear shaft stack and service rules
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2026-08-27 Document Rev.AQ serviceable wheel hub and side cover interface
2026-08-27 Add Rev.AR FreeCAD socket and service clearance checker
2026-08-27 Add Rev.AS procurement freeze for bearing seal and M8 hardware
2026-08-27 Freeze Rev.AU rear shaft M8x1.25 wheel retention geometry
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2026-08-27 Add Rev.AW rear output shaft drawing-candidate CAD generator
2026-08-27 Add Rev.AW machining drawing specification for rear output shaft
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2026-08-27 Add Rev.BA controlled rear seal pressure and leak test procedure
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2026-08-27 Document Rev.BB PX-1 pressure-body architecture and next gates
2026-08-27 Freeze verified LEMO rear receptacle dimensions and cable-plug selection rule
2026-08-27 Document Rev.BE manual lift and quick-release camera interface requirements
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2026-08-27 Add Rev.BG TILT/ROLL camera-head clearance envelope
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2026-08-27 Add Rev.BJ real-envelope camera head internal packaging model
2026-08-27 Document Rev.BJ camera drive packaging and engineering holds
2026-08-27 Add Rev.BK exact N20 motor selection, TILT torque budget and ROLL gearing
2026-08-27 Add Rev.BL camera ROLL involute gears and TILT worm packaging study
2026-08-27 Document Rev.BL camera ROLL gear freeze and TILT worm hold
2026-08-27 Add Rev.BN supported TILT worm shaft and coupling model
2026-08-27 Add Rev.BN TILT torque, support and validation requirements
2026-08-27 Add Rev.BO TILT bearing, coupler and HOME-sensor selection
2026-08-27 Add Rev.BP complete TILT module packaging and kinematic model
2026-08-27 Add Rev.BQ combined TILT ROLL camera head packaging model
2026-08-27 Document Rev.BQ combined camera head packaging and revised length
2026-08-27 Add Rev.BR dynamic DN150 sampled clearance sweep
2026-08-27 Add Rev.BT DN150 solid sweep checker using current lift coordinates
2026-08-27 Add Rev.BU camera head shell, window, LED and quick-release packaging
2026-08-27 Document Rev.BU camera head shell and preferred internal roll cartridge architecture
2026-08-27 Add Rev.BW ROLL cartridge service, retention and wiring architecture
2026-08-27 Add Rev.CB compact Ethernet roll joint and camera-size correction
2026-08-27 Add Rev.CC compact 32mm H265 IP camera selection
2026-08-27 Add Rev.CD digital ROLL cartridge with 32mm IP camera and Ø22 Ethernet slip-ring
2026-08-27 Document Rev.CD digital ROLL repack and bearing change
2026-08-27 Add Rev.CH rugged PX-1 tether cable architecture and sourcing targets
2026-08-27 Add Rev.CI tether voltage-drop study and 48V baseline
2026-08-27 Add Rev.CJ provisional 48V power budget and converter sizing
2026-08-27 Add Rev.CL 48 V input protection and fused distribution architecture
2026-08-27 Add Rev.CM traction motor power stage and braking protection architecture
2026-08-27 Add Rev.CN current sensing and hardware E-STOP architecture
2026-08-27 Add Rev.CO traction contactor and hardware E-stop driver architecture
2026-08-27 Add Rev.CQ JGB37-520 24V ratio selection based on manufacturer data
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2026-08-27 Add Rev.CS serviceable gear-only 4WD side gearbox concept
2026-08-27 Replace cassette concept with integrated serviceable 4WD geartrain
2026-08-27 Add sealed pressurized side gear covers with gaskets
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2026-08-27 Add Rev.CW six-wheel geartrain and pressurized side-bay layout
2026-08-27 Add Rev.CX six-wheel shaft seal and bearing stack
2026-08-27 Add Rev.CZ six-wheel geartrain and motor packaging freeze
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2026-08-27 Add Rev.DB CadQuery master with verified six-wheel packaging
2026-08-27 Correct PX-1 drive architecture using uploaded CRP150 motor and housing drawings
2026-08-27 Add Rev.DE CRP150-style manual gas-spring camera lift architecture
2026-08-27 Add Rev.DG CRP150-style lift and DN150 camera sweep check
2026-08-27 Select JGB37-555 24V ratio56 as stronger traction baseline
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2026-08-27 Add Rev.DL DN150 wheel-profile correction
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2026-08-27 Correct Rev.DL wheel geometry to actual DN150 contact condition
2026-08-27 Correct DN150 checker to solve pipe axis from wheel contact
2026-08-27 Add Rev.DQ corrected DN150 wheel-contact and camera sweep
2026-08-27 Add Rev.DP corrected six-wheel CRP150-style FreeCAD master
2026-08-27 Add Rev.DQ corrected camera sweep checker
2026-08-27 Add Rev.DR rugged digital tail connector shortlist
2026-08-27 Add Rev.DS three-zone pressure manifold and service design
2026-08-27 Rev.DT correct six-wheel side drive to five equal Z50 gears
2026-08-27 Rev.DV define traction current and bevel torque protection limits
2026-08-27 Rev.DW simplify pressure architecture for DN150 bevel packaging
2026-08-27 Rev.DX integrate Z50 side train, KHK bevels, opposite-end motors and DN150 sweep
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2026-08-27 Add corrected Rev.DX six-wheel CRP150-style FreeCAD master
2026-08-27 Correct Rev.DX packaging check to current geometry
2026-08-27 Add Rev.EC traction torque and current limit policy
2026-08-27 Add Rev.DY center input shaft and bevel stack
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2026-08-27 Correct Rev.EA O-ring interpretation and DN150 screw-head rule
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2026-08-27 Add Rev.EF central bevel output and side-drive coupling
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2026-08-27 Add Rev.EI main housing and service cover architecture
2026-08-27 Add Rev.EJ integrated CRP150-style drivetrain and housing master
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2026-08-27 Rev.ES move traction input to X200 and rearward motor pack
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2026-08-27 Add Rev.ET machinable three-zone pressure body FreeCAD source
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2026-08-27 Add Rev.FH axle-flange and side-cover manufacturing drawing data
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2026-08-27 Add Rev.FT prototype datum and tolerance table
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2026-08-27 Rev.GB correct traction motor packaging to 32mm planetary class
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2026-08-28 Add Rev.GP corrected internal packaging CAD
2026-08-28 Correct PX1 internal packaging to rearward 32mm motors
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2026-08-28 Correct PX1 power budget to active two-motor architecture
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2026-08-28 Add Rev.GU drivetrain direction and folded-camera wet-deck correction
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2026-09-01 Rev.PR freeze corrected rear-wheel input crawler master
2026-09-11 reference: correct CRP-150 side-drive bearing quantity evidence
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2026-09-11 Rev.B WB10: select three-zone pressure and leak telemetry architecture
2026-09-11 Rev.B WB10: move pressure to I2C and add sampled leak probe pins
    [board_map_f446.h]
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2026-09-11 WB11: enforce coast-before-reverse and bus/current traction safety
    [traction_bts7960.c]
2026-09-11 WB11: refine traction safety implementation and fault reset conditions
    [traction_bts7960.c]
2026-09-11 Rev.B WB12: promote corrected CAM026-inspired camera electrical baseline
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2026-09-11 Rev.B WB14: freeze RunCam camera and fixed-shell LED lighting architecture
2026-09-11 Rev.B WB13A: correct camera slip-ring candidate after fixed-shell load audit
2026-09-11 Rev.B WB14: move camera control/lighting fixed-side and reduce roll ring to camera power+CVBS
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2026-09-11 Rev.B WB13A correct camera slip-ring load after WB14
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2026-09-11 Rev.B: correct TILT worm wheel for 8 mm sealed pivot
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2026-09-11 Rev.B WB19: integrate camera lift body and R55 head harness
    Correct the WB16 harness-motion proxy, integrate the WB18 camera with the Rev.PR body obstacle, and add R55 routing validation while retaining MANUFACTURING HOLD.
2026-09-11 Rev.B WB20: correct wet bay TILT stack packaging and gas spring
    Fix full-crawler yoke/body/Z50 integration omitted by WB18/WB19, lower the front wet bay, recess the TILT stack, repack selected electronics and add a real ACE gas-spring screen while retaining MANUFACTURING HOLD.
2026-09-11 Rev.B WB21: constant-length camera head harness at lift pivot
    Replace the WB19 upper-body slack loop with one controlled pivot flex zone, add the CF99.PLUS.01.08 technical cable baseline and LAPP M16 body ingress, and retain manufacturing/procurement holds.
2026-09-13 Rev.B WB22A: document lift-camera carrier correction
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2026-09-13 Rev.B WB23E: correct pressure-service cover BOM dimensions
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2026-09-14 Rev.B WB23G: correct camera lift interface to six-core harness
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2026-09-14 Rev.B WB23G: correct service BOM to six-core harness
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2026-09-14 PX1: consolidate current master and correct side-drive bearing count
2026-09-14 PX1: replace validation with scoped HOLD-aware current result
2026-09-14 PX1: update current BOM and corrected bearing quantities
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2026-09-14 PX1: replace executable current master with corrected final-assembly model
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2026-09-14 Restore single PX1 current master and correct CRP150 source quantities
2026-09-14 Recover source-scaled CRP150 current assembly, 127-line BOM and reproducible HOLD export
    [PX1_Current_BOM.csv]
2026-09-14 Export current PX1 reconstruction; manufacturing HOLD
    [HOLD_AXLE_FLANGE_-1_150.0_GRAPHIC_CONTOUR.step, HOLD_AXLE_FLANGE_-1_250.0_GRAPHIC_CONTOUR.step, HOLD_AXLE_FLANGE_-1_50.0_GRAPHIC_CONTOUR.step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]
2026-09-14 Fix reported layout collisions and add current electrical/pressure diagrams
    [PX1_Current_BOM.csv]
2026-09-14 Fix Cyrillic diagrams and finish PDF layout review [skip ci]
    Regenerate the 16-page documentation from the checked-in images of the validated master. Preserve all STEP/STL geometry and the 46-page CAD drawing PDF. Record visual review scope and refreshed manifest. Manufacturing remains HOLD.
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2026-09-16 A0: add printable drivetrain fixture and source-match CAD
2026-09-16 CI: generate PX1 A0 drivetrain fixture package
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2026-09-16 Control: correct motor decision and authorize A1 rolling fixture
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2026-09-16 CI: make current export artifact-only to avoid push races
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2026-10-21 PX1 A0/A1: исправить посадки, стяжки и печатный CAD стенда
    * fix(fixtures): preserve bearing pockets, align crossbar bolts, flatten STLs
    * fix(fixtures): preserve bearing pockets, align crossbar bolts, flatten STLs
    * test(a1): reject nonmanifold prints, misplaced holes and standing STL exports
    * ci(a1): build fit-check on PR and validate printable mesh geometry
    * docs(a1): corrected hole mismatch and remaining bench limitations
2026-10-22 PX1: зафиксировать дефект посадки двух моторов в A1.5
    * audit: reproduce critical A1.5 motor-to-bearing-plate collision as CAD booleans
    * engineering: document verified A1.5 motor clearance failure and redesign constraint
    * ci: reproduce A1.5 motor fit blocker with actual CAD boolean test
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2026-11-05 Note possible ARM boot instruction and link to next read-only FS probe
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2026-11-05 Compare offline CCU image with official Freescale BSP and stage passive inventory
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2026-11-05 Record full 1,029-entry Mini-Cam factoryupdate ZIP scan and absence of CAD files
2026-11-05 Index verified public Proteus service sources, CAN bus and test fixtures
2026-11-05 Add verified older Proteus service and troubleshooting manuals plus 6-core cable specification
